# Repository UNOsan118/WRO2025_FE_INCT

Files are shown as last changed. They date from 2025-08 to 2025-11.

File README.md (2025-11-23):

# WRO 2025 Future Engineers: Team Ishikawa KOSEN Flag of Japan

<p align="center">
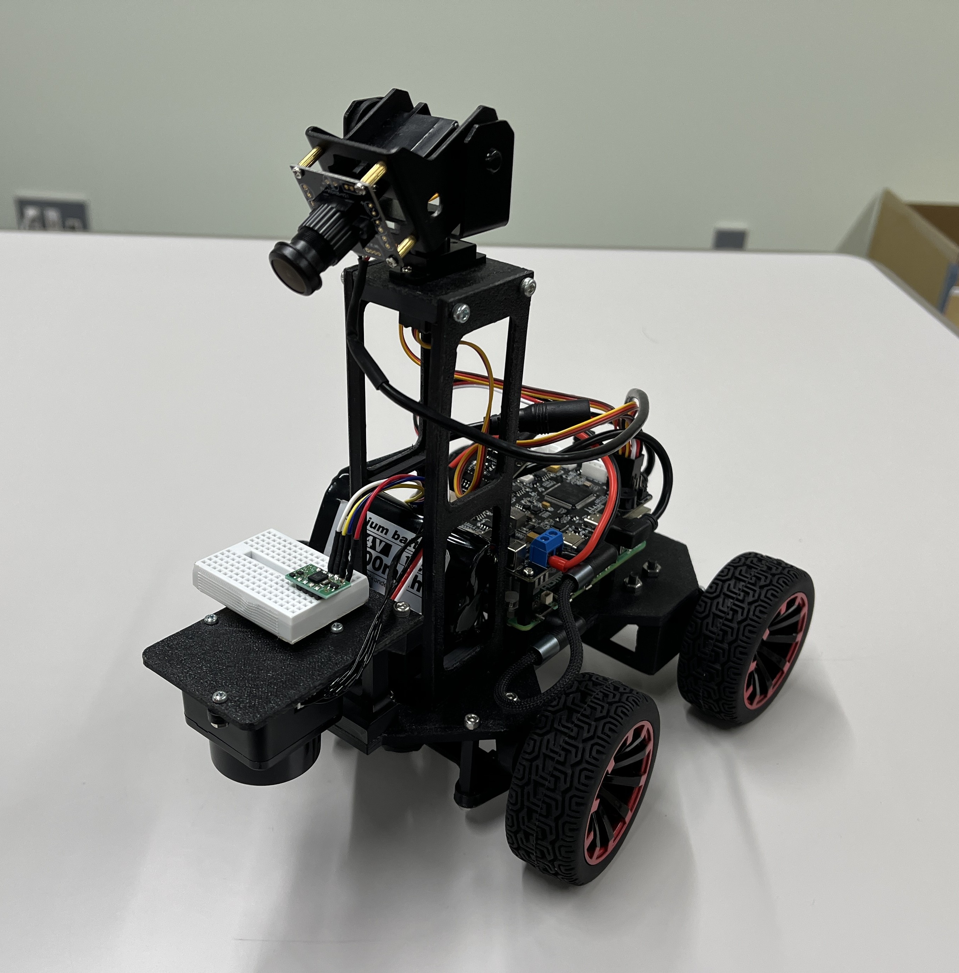
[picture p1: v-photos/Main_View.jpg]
Main_View
  
  <br>
</p>

<!-- Social media badges (optional but nice) -->



This is the official repository for **Team Ishikawa KOSEN**, representing Japan in the World Robot Olympiad (WRO) 2025 Future Engineers category. This document provides a comprehensive overview of our robot's design, strategy, and implementation, developed by Shinichi Uno and Kosei Takano.

---

## 1. Team Members & Roles

## 1.1 Team Introduction

We are Team Ishikawa KOSEN, the representatives of Japan for the WRO 2025 Future Engineers category. After winning a highly competitive national competition, we are deeply honored to compete on the world's highest stage. Our team consists of two students and one coach from the National Institute of Technology (KOSEN), Ishikawa College, an institution renowned for its rigorous, project-based engineering curriculum. It is through this hands-on approach—where theoretical knowledge is immediately applied to solve complex, real-world challenges—that we have honed the skills necessary to excel. We are fully prepared and determined to claim first place in this international competition!

<p align="center">
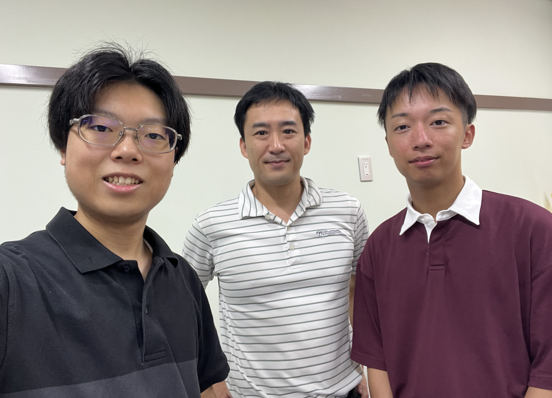
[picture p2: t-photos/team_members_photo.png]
Team members photo
  
  <br>
</p>

*   **Shinichi Uno:** Lead Programmer, Strategist & Co-Mechanical Designer
    *   *Major: Advanced Electronic and Mechanical Engineering, 2nd Year*
    *   *Born: January 18, 2004*

<p align="center">
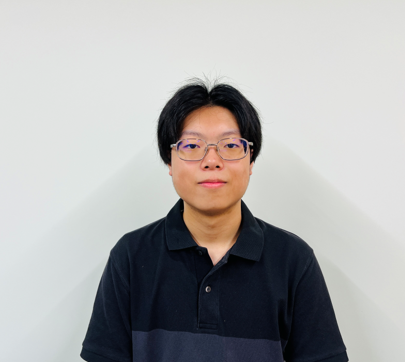
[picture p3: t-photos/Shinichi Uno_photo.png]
Team members photo
  
  <br>
</p>

*   **Kosei Takano:** Lead Mechanical Designer & Systems Integrator
    *   *Major: Advanced Electronic and Mechanical Engineering, 2nd Year*
    *   *Born: May 29, 2003*

<p align="center">
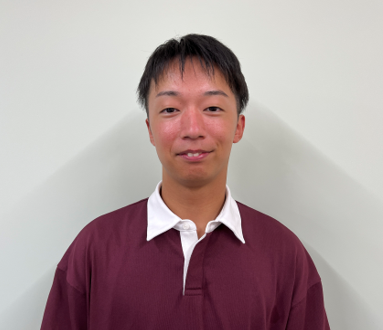
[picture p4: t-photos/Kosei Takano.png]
Team members photo
  
  <br>
</p>

*   **Makoto Koshino:** Team Coach
    *   *Professor, Department of Electronics and Information Engineering*

<p align="center">
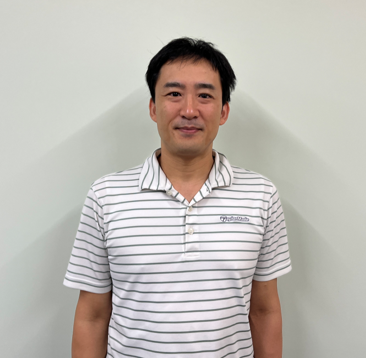
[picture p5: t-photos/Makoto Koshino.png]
Team members photo
  
  <br>
</p>

---

## 2. Repository Structure

A brief guide to navigating our project repository.

*   `src/`: Contains the core ROS 2 source code, including our main `obstacle_navigator_node`.
*   `models/`: 3D CAD files for all custom-designed and 3D-printed parts.
*   `schemes/`: Circuit diagrams, system architecture diagrams, and state-machine flowcharts.
*   `v-photos/`: A gallery of our robot from all angles.
*   `t-photos/`: Photos of our team.
*   `video/`: Performance videos demonstrating the robot's capabilities.
*   `README.md`: This file, detailing our entire engineering process.

---

## 3. Bill of Materials (BOM)

The table below lists all the major electrical and mechanical components used to build our robot. Each component was carefully selected to meet our performance and reliability requirements. Direct links to product pages or datasheets are provided to ensure the reproducibility of our design.

| Component | Image | Quantity | Link / Datasheet |
| :--- | :---: | :---: | :--- |
| **Controller & Interface** | | | |
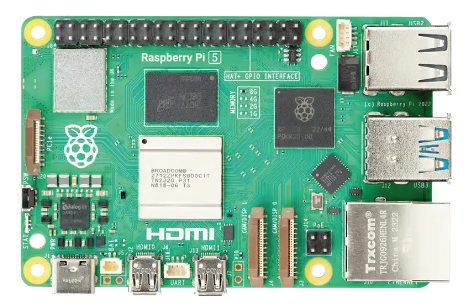
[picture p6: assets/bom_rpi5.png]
| Raspberry Pi 5 |  | 1 | [Official Page](https://www.raspberrypi.com/products/raspberry-pi-5/) |
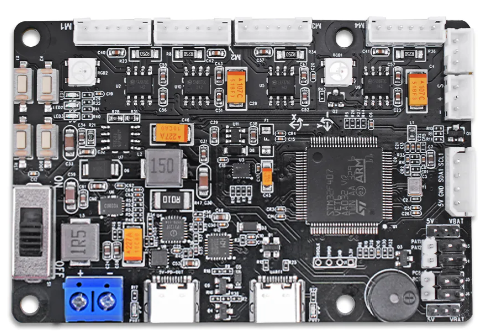
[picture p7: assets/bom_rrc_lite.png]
| RRC Lite Controller |  | 1 | [Official Page](https://www.hiwonder.com/products/rrc-lite) <br> *(Part of [MentorPi A1 kit](https://www.hiwonder.com/products/mentorpi-a1-monocular-camera-version?variant=41370001244247))*|
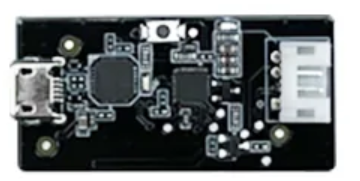
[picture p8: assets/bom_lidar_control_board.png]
| Control Board for LiDAR |  | 1 | *(Part of [MentorPi A1 kit](https://www.hiwonder.com/products/mentorpi-a1-monocular-camera-version?variant=41370001244247) and [LiDAR kit](https://www.hiwonder.com/products/ld19-d300-lidar?_pos=1&_sid=6968f314c&_ss=r) )*|
| **Sensors** | | | |
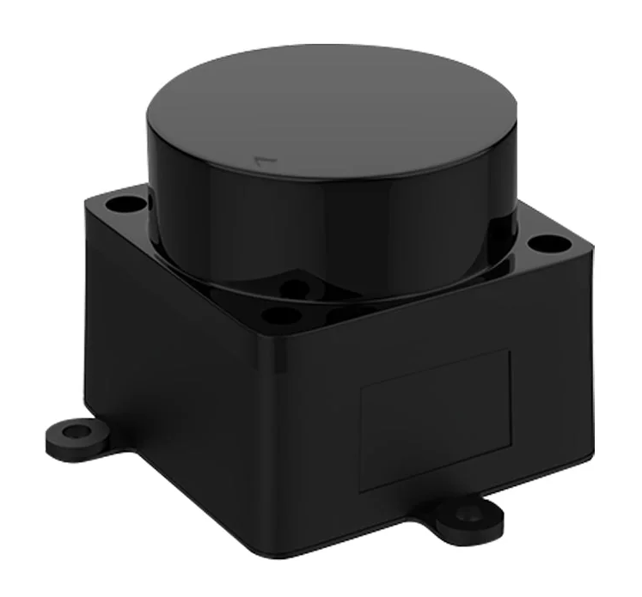
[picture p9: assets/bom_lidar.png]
| STL-19P D500 LiDAR |  | 1 | [Product Page](https://www.hiwonder.com/products/ld19-d300-lidar?_pos=1&_sid=6968f314c&_ss=r) <br> *(Part of [MentorPi A1 kit](https://www.hiwonder.com/products/mentorpi-a1-monocular-camera-version?variant=41370001244247))*|
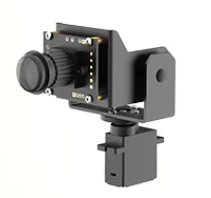
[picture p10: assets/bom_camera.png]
| 2DOF Monocular Camera |  | 1 | [Product Page](https://www.hiwonder.com/products/mentorpi-a1-monocular-camera-version?variant=41370001244247) <br> *(Part of [MentorPi A1 kit](https://www.hiwonder.com/products/mentorpi-a1-monocular-camera-version?variant=41370001244247))*|
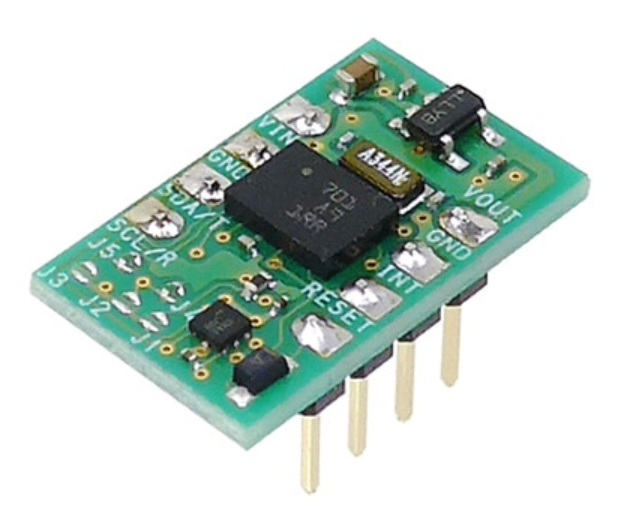
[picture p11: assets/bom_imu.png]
| BNO055 IMU |  | 1 | [Product Page](https://akizukidenshi.com/catalog/g/g116996/) |
| **Propulsion & Steering System** | | | |
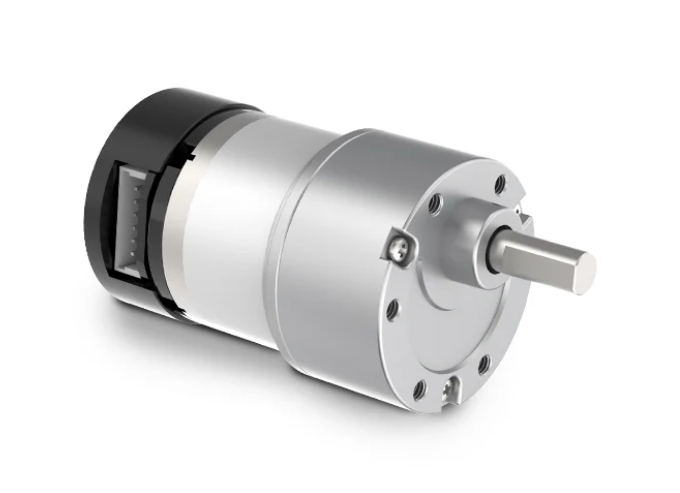
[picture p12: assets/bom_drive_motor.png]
| DC Geared Motor w/ Encoder| | 1 | [Product Page](https://www.hiwonder.com/products/hall-encoder-dc-geared-motor?variant=40451123675223) <br> *(Part of [MentorPi A1 kit](https://www.hiwonder.com/products/mentorpi-a1-monocular-camera-version?variant=41370001244247))*|
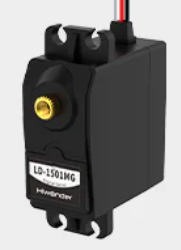
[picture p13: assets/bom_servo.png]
| Hiwonder LFD-01 Servo|  | 1 | [Product Page](https://www.aliexpress.com/i/3256805777087496.html?gatewayAdapt=jpn2glo4itemAdapt) <br> *(Part of [MentorPi A1 kit](https://www.hiwonder.com/products/mentorpi-a1-monocular-camera-version?variant=41370001244247))*|
| **Power System** | | | |
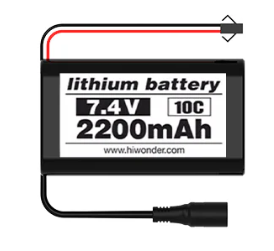
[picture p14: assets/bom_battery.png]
| 7.4V 2200mAh LiPo Battery|  | 1 | *(Part of [MentorPi A1 kit](https://www.hiwonder.com/products/mentorpi-a1-monocular-camera-version?variant=41370001244247))* |
| **Mechanical Components** | | | |
| Differential Gears |  | 1 | [Product Page](https://www.aliexpress.com/i/3256803487389220.html?gatewayAdapt=4itemAdapt) |
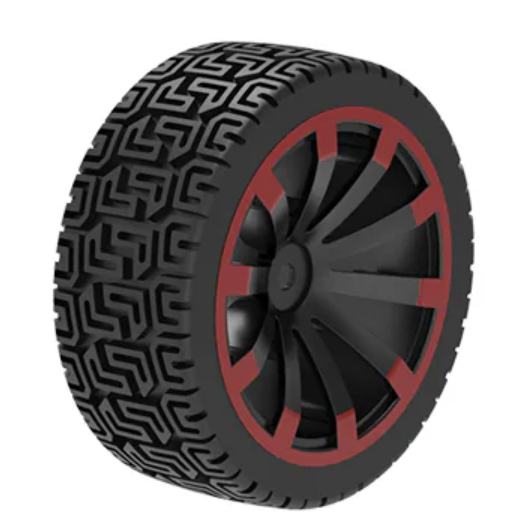
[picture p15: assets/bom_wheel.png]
| Wheels & Tires |  | 4 | *[Product Page](https://www.hiwonder.com/products/mecanum-omnidirectional-wheel-metal-coupling-motor-ros-robot-universal-wheel-smart-car-tire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) <br> (Part of [MentorPi A1 kit](https://www.hiwonder.com/products/mentorpi-a1-monocular-camera-version?variant=41370001244247))* |
| **Custom 3D-Printed Parts** | | | |
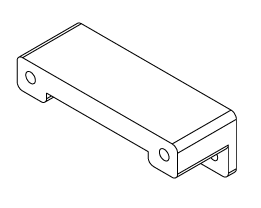
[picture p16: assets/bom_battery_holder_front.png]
| Battery Holder (Front) |  | 1 | [3D Model](models/custom_parts/cad_files/battery_holder_front.SLDPRT) / [Blueprint](models/custom_parts/blueprints/battery_holder_front.PDF) |
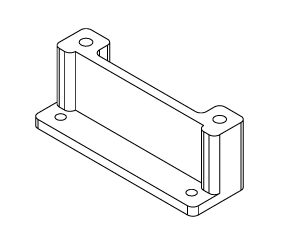
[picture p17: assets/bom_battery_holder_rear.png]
| Battery Holder (Rear) |  | 1 | [3D Model](models/custom_parts/cad_files/battery_holder_rear.SLDPRT) / [Blueprint](models/custom_parts/blueprints/battery_holder_rear.PDF) |
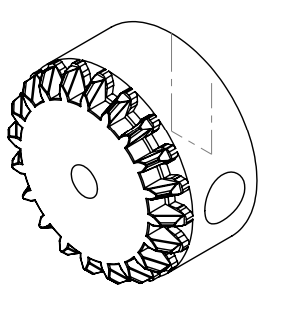
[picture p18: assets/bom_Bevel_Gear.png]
| Bevel Gear |  | 1 | [3D Model](models/custom_parts/cad_files/Bevel_Gear.SLDPRT) / [Blueprint](models/custom_parts/blueprints/Bevel_Gear.pdf) |
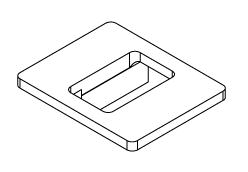
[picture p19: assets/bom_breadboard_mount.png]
| Breadboard Mount |  | 1 | [3D Model](models/custom_parts/cad_files/breadboard_mount.SLDPRT) / [Blueprint](models/custom_parts/blueprints/breadboard_mount.PDF) |
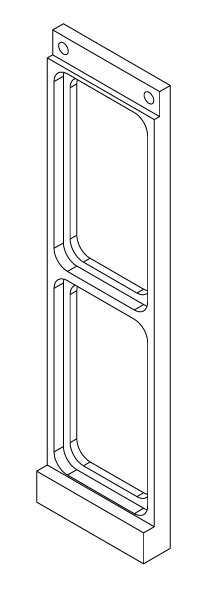
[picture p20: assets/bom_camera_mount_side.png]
| Camera Mount (Side) |  | 2 | [3D Model](models/custom_parts/cad_files/camera_mount_side.SLDPRT) / [Blueprint](models/custom_parts/blueprints/camera_mount_side.PDF) |
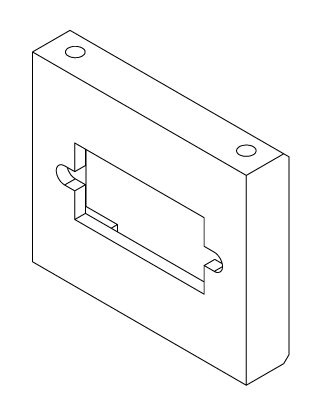
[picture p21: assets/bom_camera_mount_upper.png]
| Camera Mount (Upper) |  | 1 | [3D Model](models/custom_parts/cad_files/camera_mount_upper.SLDPRT) / [Blueprint](models/custom_parts/blueprints/camera_mount_upper.PDF) |
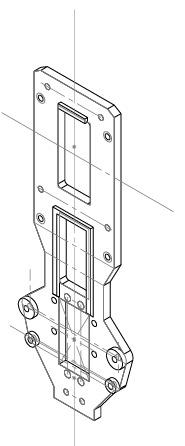
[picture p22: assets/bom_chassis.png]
| Chassis |  | 1 | [3D Model](models/custom_parts/cad_files/chassis.SLDPRT) / [Blueprint](models/custom_parts/blueprints/chassis.PDF) |
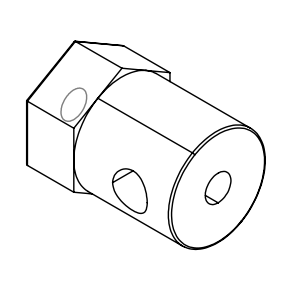
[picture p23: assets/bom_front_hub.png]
| Front Hub |  | 2 | [3D Model](models/custom_parts/cad_files/front_hub.SLDPRT) / [Blueprint](models/custom_parts/cad_files/front_hub.SLDPRT) |
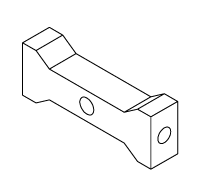
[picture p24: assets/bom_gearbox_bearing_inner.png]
| Gearbox Bearing (Inner) |  | 1 | [3D Model](models/custom_parts/cad_files/gearbox_bearing_inner.SLDPRT) / [Blueprint](models/custom_parts/blueprints/gearbox_bearing_inner.pdf) |
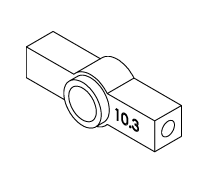
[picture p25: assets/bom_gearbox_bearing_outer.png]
| Gearbox Bearing (Outer) |  | 1 | [3D Model](models/custom_parts/cad_files/gearbox_bearing_outer.SLDPRT) / [Blueprint](models/custom_parts/blueprints/gearbox_bearing_outer.pdf) |
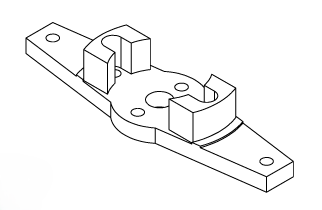
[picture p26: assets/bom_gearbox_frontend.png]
| Gearbox (Front End) |  | 1 | [3D Model](models/custom_parts/cad_files/gearbox_frontend.SLDPRT) / [Blueprint](models/custom_parts/blueprints/gearbox_frontend.PDF) |
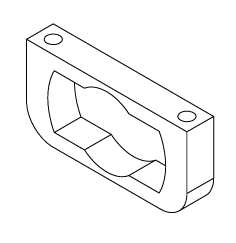
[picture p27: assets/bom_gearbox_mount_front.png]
| Gearbox Mount (Front) |  | 1 | [3D Model](models/custom_parts/cad_files/gearbox_mount_front.SLDPRT) / [Blueprint](models/custom_parts/blueprints/gearbox_mount_front.PDF) |
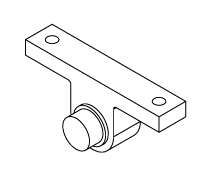
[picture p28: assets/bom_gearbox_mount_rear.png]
| Gearbox Mount (Rear) |  | 1 | [3D Model](models/custom_parts/cad_files/gearbox_mount_rear.SLDPRT) / [Blueprint](models/custom_parts/blueprints/gearbox_mount_rear.PDF) |
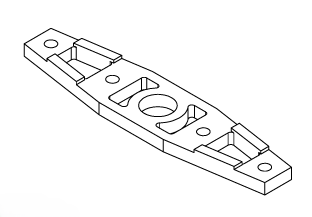
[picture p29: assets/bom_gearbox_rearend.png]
| Gearbox (Rear End) |  | 1 | [3D Model](models/custom_parts/cad_files/gearbox_rearend.SLDPRT) / [Blueprint](models/custom_parts/blueprints/gearbox_rearend.PDF) |
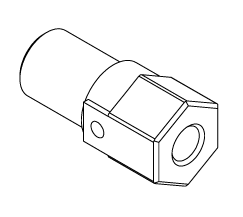
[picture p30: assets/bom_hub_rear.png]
| Hub (Rear) |  | 2 | [3D Model](models/custom_parts/cad_files/hub_rear.SLDPRT) / [Blueprint](models/custom_parts/blueprints/hub_rear.pdf) |
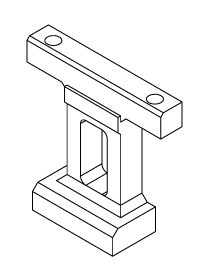
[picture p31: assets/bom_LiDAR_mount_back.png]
| LiDAR Mount (Back) |  | 1 | [3D Model](models/custom_parts/cad_files/LiDAR_mount_back.SLDPRT) / [Blueprint](models/custom_parts/blueprints/LiDAR_mount_back.PDF) |
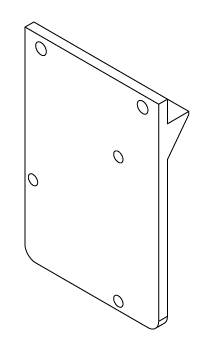
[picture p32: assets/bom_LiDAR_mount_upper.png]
| LiDAR Mount (Upper) |  | 1 | [3D Model](models/custom_parts/cad_files/LiDAR_mount_upper.SLDPRT) / [Blueprint](models/custom_parts/blueprints/LiDAR_mount_upper.PDF) |
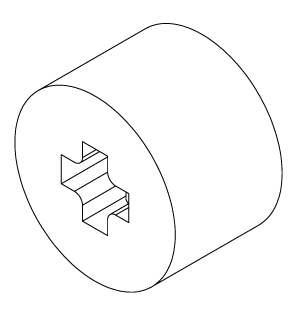
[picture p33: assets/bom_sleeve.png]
| Sleeve |  | 2 | [3D Model](models/custom_parts/cad_files/sleeve.SLDPRT) / [Blueprint](models/custom_parts/blueprints/sleeve.pdf) |
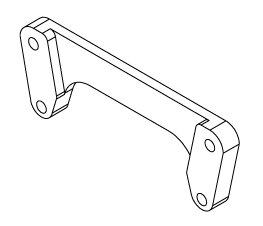
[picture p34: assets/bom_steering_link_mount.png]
| Steering Link Mount |  | 1 | [3D Model](models/custom_parts/cad_files/steering_link_mount.SLDPRT) / [Blueprint](models/custom_parts/blueprints/steering_link_mount.pdf) |

---

## 4. Vehicle Overview & Photos

A high-level introduction to our robot's design philosophy and key features.

| Front_View | Right_View | Rear_View |
| :--: | :--: | :--: |
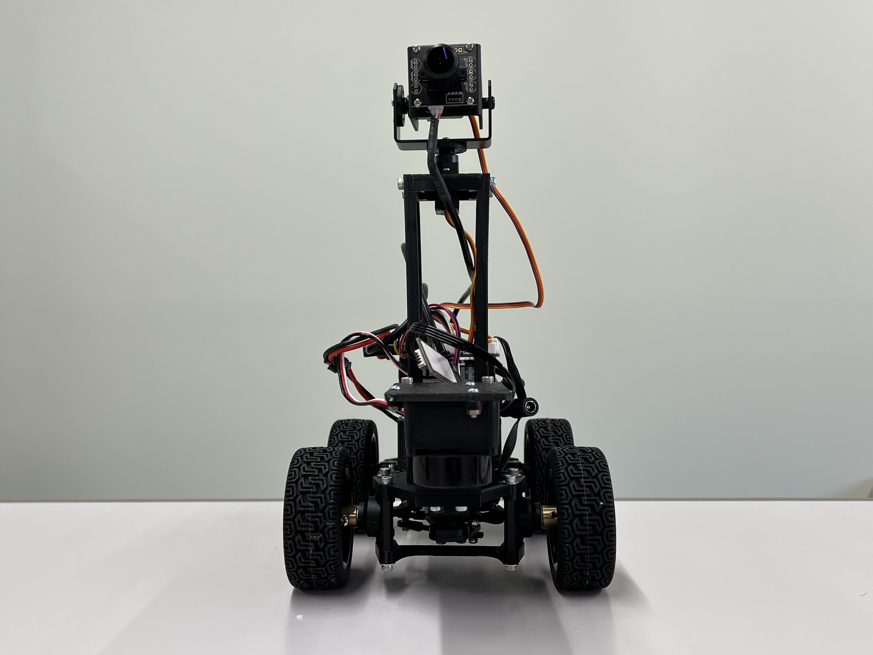
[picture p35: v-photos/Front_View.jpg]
Front_View
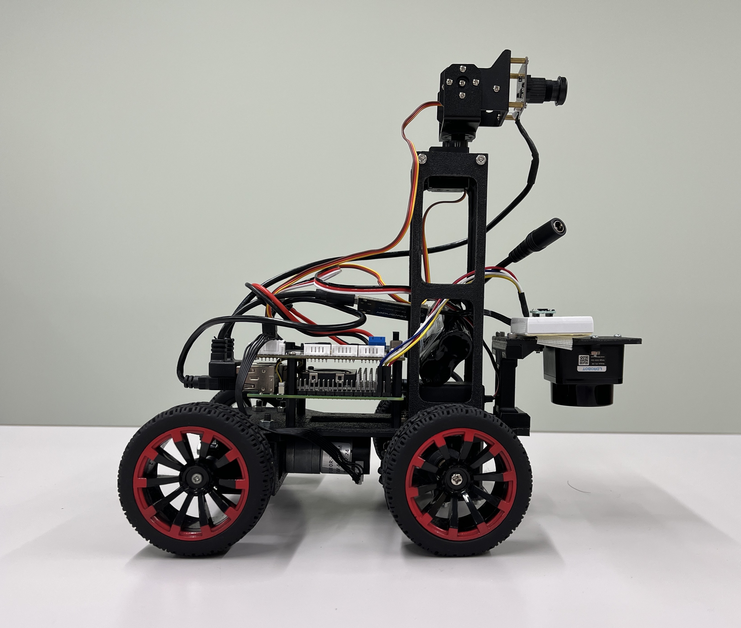
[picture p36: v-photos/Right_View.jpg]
Right_View
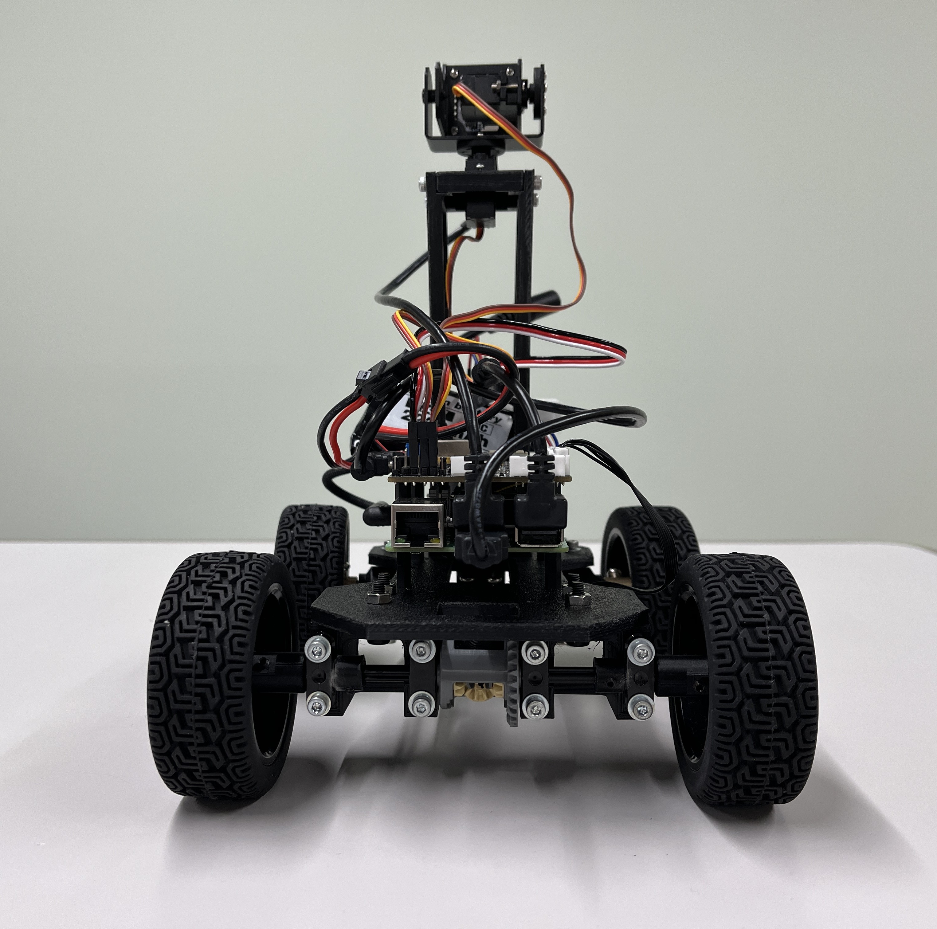
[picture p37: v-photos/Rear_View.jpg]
Rear_View
|  |  |  |
| Left_View | Top_View | Bottom_View |
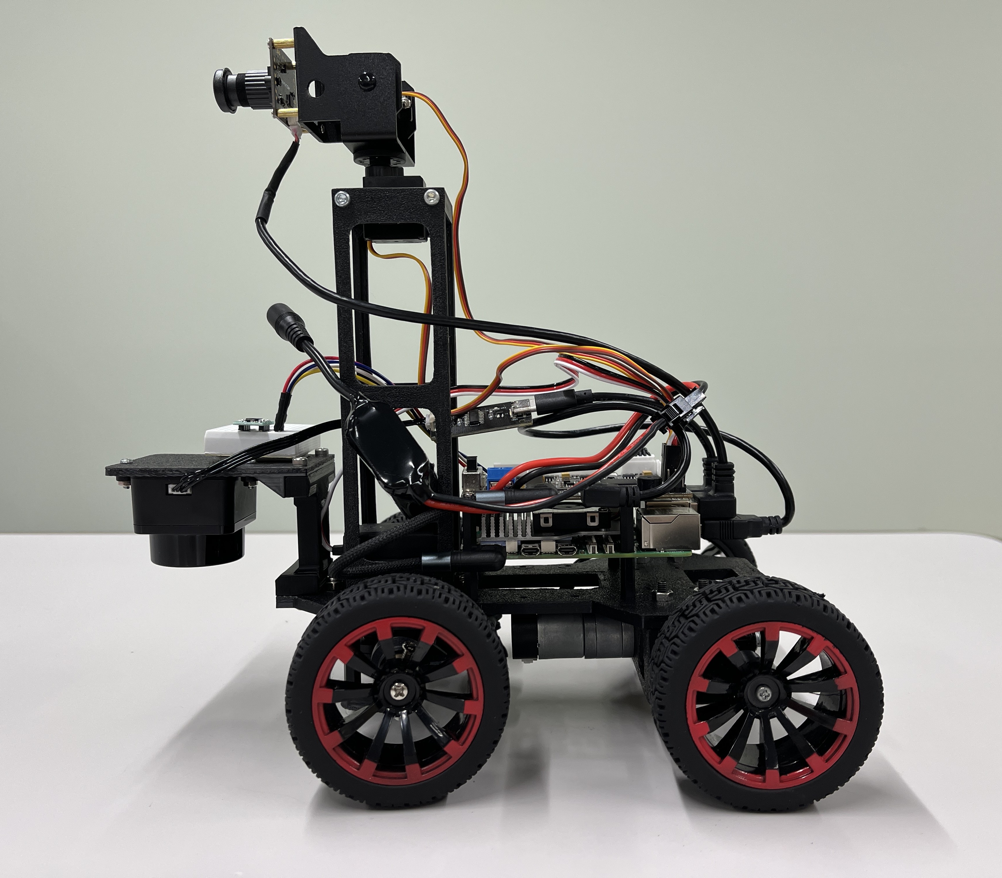
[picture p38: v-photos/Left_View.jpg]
Left_View
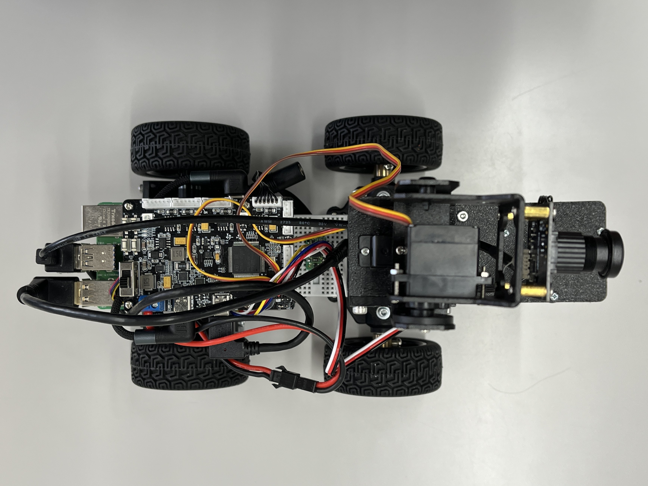
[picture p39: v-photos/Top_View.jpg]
Top_View
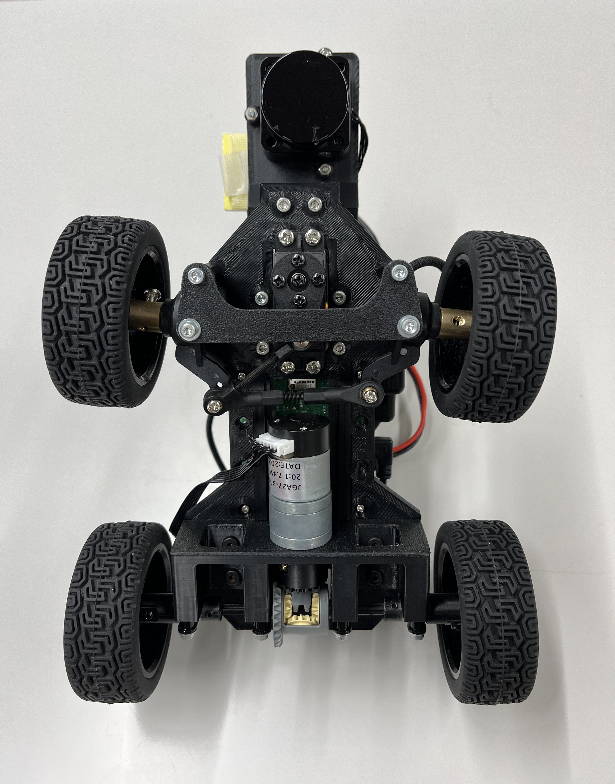
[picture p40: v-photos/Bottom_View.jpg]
Bottom_View
|  |  |  |

<p align="center">
  Power Switch and Start Button
  <br>
  <em>Power Switch and Start Button</em>
</p>

---             

## 5. Mobility Management

This section details our robot's mechanical framework, its propulsion system, and the mechanisms for directional control. Our design philosophy emphasizes precision, stability, and agile control on the competition field.

### 5.1. Chassis Design

Our robot's development began with the **Hiwonder MentorPi A1** as a base platform, which we selected for its robust initial structure. However, through extensive testing and iteration, our design has evolved into a **unique, custom chassis** that, while inspired by the original, is now tailored specifically to our strategic needs.

### 5.2. Drive Mechanism: A Custom Monoshock Differential System

#### 5.2.1. Development Story: Integrating Propulsion, Suspension, and Rule Compliance

The stock MentorPi A1 chassis featured a dual-motor drive system, which is not permitted under WRO rules as it constitutes an "electronic differential." Our primary engineering goal was to not only achieve rule compliance with a mechanical solution but to **seize this opportunity to innovate**. We decided to design a completely new rear assembly that would integrate three critical functions into one compact unit: **propulsion, differential action, and suspension**.

Our solution is a custom-designed and 3D-printed gearbox that houses a **single DC motor** and a reliable **LEGO Technic differential gear set**. Most importantly, the entire gearbox assembly is mounted to the chassis via a pivot and acts as a swingarm, effectively creating a **monoshock suspension system** for the rear axle.

#### 5.2.2. Functional Deep Dive: The Integrated Gearbox and Suspension

This integrated design offers significant performance advantages:

*   **Mechanical Differential:** The combination of our custom bevel gear and the LEGO differential ensures rule compliance while providing smooth power distribution for stable cornering. The 3D-printed housing was meticulously designed in SOLIDWORKS to guarantee a perfect and reliable gear mesh.
*   **Monoshock Suspension:** As shown in the images below, the gearbox pivots vertically, allowing the rear wheels to absorb imperfections on the track surface. This ensures that the robot can continue its run reliably even if there are unexpected bumps or irregularities on the course.

<p align="center">
  Top-down view of the custom differential gearbox
  <br>
  <em>Top-down view showcasing the custom bevel gear (top, black) meshing with the LEGO differential gear set (center, gold/grey).</em>
</p>

<p align="center">
  Rear suspension in neutral position
  Rear suspension in compressed position
  <br>
  <em>The integrated monoshock suspension system in action. The entire gearbox assembly pivots to absorb surface irregularities, maximizing traction.</em>
</p>

**Motor Selection Rationale:**
We selected this specific motor for three key reasons:
1.  **Integrated Encoder:** The built-in high-resolution encoder provides the precise feedback necessary for advanced PID speed control, eliminating the need for external sensors.
2.  **High Torque:** The 1:20 gear ratio provides sufficient torque to ensure powerful acceleration and stable performance, even on slight inclines.
3.  **Compact Form Factor:** Its compact size was ideal for our custom-designed, single-motor chassis, allowing for a clean and efficient mechanical layout.

**Motor Specifications:**
<p align="center">
  drive_motor
  Drive Motor Specifications<br>
  <em>Image and specifications sourced from <a href="https://www.hiwonder.com/products/hall-encoder-dc-geared-motor?variant=40451123675223">Hiwonder's official product page</a>.</em>
</p>

### 5.3. Steering Mechanism: Modified Ackermann Geometry

#### 5.3.1. The Challenge: A Turning Radius Unsuitable for Parking

While the stock Ackermann steering was functional for basic navigation, its limited steering angle resulted in a minimum turning radius of approximately **65 cm**. This was a critical flaw, making it physically impossible to perform the precise maneuvers required for parallel parking within a 45 cm wide space. To overcome this, a radical redesign of the entire front steering assembly was not just an optimization—it was a necessity.

#### 5.3.2. Our Solution: Vertical Motor Mount and Angled Linkage

Our solution involved redesigning the custom chassis to accommodate an innovative steering layout. By reorienting the steering servo to a **vertical position** and using an **angled transmission axis** when the wheels are straight, we achieved two critical goals simultaneously:

1.  **Space Optimization:** This compact vertical layout freed up significant space, allowing for a much greater range of motion for the steering linkage without mechanical interference.
2.  **Maximized Steering Angle:** The new geometry dramatically increased the maximum steering angle.

This redesign, while reusing most of the original mechanical linkage components, was only made possible by our custom 3D-printed chassis and mounts. The result is a steering system that achieves an incredible **minimum turning radius of just 15 cm**—a reduction of over 75%. This exceptional agility is the key enabler for our successful unparking and parking strategies.

*(Note: The evolution of our custom chassis to support this mechanism is detailed in **Section 8: Engineering Design & Manufacturing**.)*

<p align="center">
  Steering mechanism in neutral position
  Steering mechanism at full left lock
  Steering mechanism at full right lock
  <br>
  <em>Our custom steering assembly. From left to right: Neutral position showing the angled linkage, and the significantly increased maximum steering angles at full left and right lock.</em>
</p>

#### 5.3.3. Actuator and Kinematic Model

To maximize our robot's agility, we modified the stock **Ackermann steering mechanism** provided by the base vehicle. Our primary goals were to **increase the maximum steering angle** and improve overall turning precision.

*   **Principle:** The Ackermann geometry is designed so that during a turn, the inner front wheel pivots at a sharper angle than the outer wheel. This ensures that the normal lines of all four wheels intersect at a single Instantaneous Center of Rotation (ICR), minimizing tire slippage.
*   **Effect:** By adhering to this principle while modifying the linkage for a greater steering range, we have achieved exceptionally smooth and predictable cornering, especially in tight turns. This allows for more energy-efficient and faster navigation through the course.

The steering is actuated by a **Hiwonder LFD-01 Anti-blocking Servo**.

**Servo Selection Rationale:**
Our choice of this servo was deliberate, focusing on reliability and power.
1.  **High Torque & Metal Gears:** To handle the stresses of rapid, precise steering adjustments at speed, we needed a servo with high torque and durable metal gears. This prevents gear stripping, a common failure point with standard servos.
2.  **Anti-Blocking Feature:** This servo includes a built-in protection circuit that prevents damage if the steering mechanism becomes stalled or blocked, significantly increasing the robot's overall robustness during long runs.

**Motor Specifications:**
<p align="center">
  Steering Motor Specifications<br>
<em>Image and specifications sourced from <a href="https://www.hiwonder.com/products/ackermann-steering-chassis?variant=40382428348503">Hiwonder's official product page</a>.</em>
</p>

#### Kinematic Model

To mathematically model our robot's motion and ensure pure rolling without lateral slip, we applied the following kinematic principles based on the Ackermann model.

<p align="center">
  Ackermann Kinematic Model
</p>

**Key Parameters:**
*   **θ:** Front wheel steering angle (rad).
*   **V:** Linear velocity of the vehicle (m/s), with V<sub>L</sub> and V<sub>R</sub> being the left and right rear wheel velocities.
*   **D:** Track width of the vehicle (m).
*   **H:** Wheelbase of the vehicle (m).
*   **R:** Turning radius of the vehicle (m), with R<sub>L</sub> and R<sub>R</sub> being the radii for the left and right wheels.
*   **ω:** Angular velocity of the vehicle (rad/s).

**Core Formulas:**

1.  **Angular Velocity Consistency:** The angular velocity is consistent across the vehicle.
    <p align="center">
      Formula for Angular Velocity
    </p>

2.  **Relationship between Steering Angle and Turning Radius:** The turning radius is geometrically related to the steering angle and wheelbase.
    <p align="center">
      Formula for Turning Radius
    </p>
    
3.  **Individual Wheel Velocities:** By knowing the wheelbase, track width, vehicle speed, and servo steering angle, we can calculate the required velocity for each rear wheel. This difference in speed is physically realized by our differential gearbox.
    *   **Left Wheel Velocity (V<sub>L</sub>):**
        <p align="center">
          Formula for Left Wheel Velocity
        </p>

    *   **Right Wheel Velocity (V<sub>R</sub>):**
        <p align="center">
          Formula for Right Wheel Velocity
        </p>

This mathematical model is fundamental to how our `ros_robot_controller` translates high-level velocity commands into precise, differential wheel speeds, enabling accurate path following.

---

## 6. Power and Sense Management

This section details the robot's "lifeline," its power system, and its "senses," the suite of sensors that enables it to perceive the environment. A stable power supply and accurate environmental awareness are the most critical physical foundations for our autonomous navigation strategy.

### 6.1. Power System

**The Challenge:**
An autonomous robot must reliably power a powerful computational core (SBC), multiple sensors, and high-torque motors simultaneously. A significant challenge is the voltage drop that occurs during motor acceleration, which can lead to critical failures like SBC reboots or sensor errors.

**Our Solution:**
To overcome this, we have built a robust power system by combining reliable, high-performance components.

**1. Battery Selection:**
Our primary power source is a **7.4V 2200mAh 10C LiPo Battery**.

*   **Selection Rationale:**
    *   **Sufficient Capacity:** The 2200mAh capacity ensures stable performance throughout the entire duration of a competition run.
    *   **High Discharge Rate:** A high C-rate of `10C` allows the battery to comfortably handle the large peak currents demanded by the motors during acceleration, minimizing voltage drops.
    *   **Integrated BMS:** The battery includes a built-in Battery Management System (BMS) that protects against over-charge, over-discharge, over-current, and short circuits, significantly enhancing safety during testing and competition.

<p align="center">
  7.4V 2200mAh LiPo Battery
</p>

**2. Power Distribution and Stabilization:**
Power from the battery is distributed to our main components—the **Raspberry Pi, motors, and LiDAR**—via the **Hiwonder RRC Lite Controller**.

*   **Role:** This controller acts as an intelligent hub, providing stable, regulated power to these power-hungry components.
*   **Key Advantage:** A critical feature of this controller is its support for the **Power Delivery (PD) protocol**, enabling it to supply a stable **5V/5A** current to the Raspberry Pi 5. This powerful supply capability isolates the Raspberry Pi from voltage sags caused by motor operation, eliminating the risk of unexpected shutdowns or system instability. This forms the bedrock of our robot's high reliability.

<p align="center">
  RRC Lite Controller
</p>

### 6.2. Sensor Suite

Our robot fuses data from multiple sensors, each with a distinct role, to build a comprehensive and accurate understanding of its environment. All sensor data is aggregated in real-time by our main `ObstacleNavigatorNode` via ROS 2 topics to inform its navigation decisions.

#### STL-19P D500 LiDAR

<p align="center">
    STL-19P D500 LiDAR
    LiDAR Specifications
    <em><br>Image and specifications sourced from the <a href="https://www.hiwonder.com/products/ld19-d300-lidar?_pos=1&_sid=6968f314c&_ss=r">official product page</a>.</em>
</p>

**Role:** This is our primary sensor for environmental mapping. It provides 360-degree distance information, which is fundamental for wall detection, corner detection, and initial obstacle localization.

*   **Selection Rationale:** We chose this model for its high-speed, 360-degree scanning capability and its excellent ROS 2 driver support, which facilitated easy integration. Its TOF (Time of Flight) technology also ensures stable and reliable measurements.
*   **Software Integration:** Data from the `/scan` topic is fused with IMU data in our `get_distance_at_world_angle()` function. This corrected data serves as the core input for our `_execute_pid_alignment()` (wall-following) and `_check_for_corner()` (corner detection) algorithms.

*Code Snippet: Subscribing to LiDAR Data*
```python
# This code in __init__ starts listening to the /scan topic.
# The scan_callback function is called every time new data arrives.
self.scan_subscriber = self.create_subscription(
    LaserScan, 
    '/scan', 
    self.scan_callback, 
    qos_profile_lidar
)
```

#### 2DOF Monocular Camera

<p align="center">
    2DOF Monocular Camera
    Camera Specifications
    <em><br>Image and specifications sourced from the <a href="https://www.hiwonder.com/products/mentorpi-a1-monocular-camera-version?variant=41370001244247">official product page</a>.</em>
</p>

**Role:** Our vision sensor, used exclusively for identifying the **color** of obstacles.

*   **Selection Rationale:** The 170° wide-angle lens is a key feature, allowing the robot to capture a broad view of the upcoming segment during its corner scans. Its USB interface and ROS 2 compatible driver ensure seamless integration with the Raspberry Pi.
*   **Software Integration:** Image frames from the `/ascamera/...` topic are processed during the `PLAN_NEXT_AVOIDANCE` phase. Using OpenCV, we detect red and green blobs and compare their areas to determine the `avoidance_path_plan` for the next segment.

*Code Snippet: Subscribing to Camera Data*
```python
# This code in __init__ subscribes to the camera's image topic.
# The image_callback function processes the incoming video frames.
self.image_sub = self.create_subscription(
    Image, 
    '/ascamera/camera_publisher/rgb0/image', 
    self.image_callback, 
    qos_profile_img
)
```

#### IMU (BNO055)

<p align="center">
    BNO055 IMU
    Camera Specifications
    <em><br>Image and specifications sourced from the <a href="https://akizukidenshi.com/catalog/g/g116996/">official product page</a>.</em>
</p>

**Role:** This Inertial Measurement Unit measures the robot's orientation (yaw angle), acting as a crucial component that dramatically enhances navigation precision.

*   **Selection Rationale:** Although the RRC Lite Controller has an onboard IMU, we opted for the external BNO055 for its superior accuracy and stability. Its internal 9-axis sensor fusion algorithms provide a reliable, low-drift heading estimate.
*   **Software Integration:** The yaw data from the `/imu/yaw` topic is **essential for correcting the LiDAR data** in our `get_distance_at_world_angle()` function. This is how we overcome the "Black Wall Problem," ensuring accurate wall distance measurements regardless of the robot's orientation.

*Code Snippet: Subscribing to IMU Data*
```python
# This code in __init__ subscribes to the IMU's yaw topic.
# The yaw_callback function updates the robot's current heading.
self.yaw_subscriber = self.create_subscription(
    Float64, 
    '/imu/yaw', 
    self.yaw_callback, 
    10
)
```

### 6.3. Wiring Diagram

The following diagram illustrates the complete electrical connections between our core components, including the Raspberry Pi, RRC Lite Controller, battery, and all sensors. This centralized wiring, managed by the RRC Lite Controller, simplifies the overall structure and enhances reliability by minimizing potential points of failure.

<p align="center">
  Robot Wiring Diagram
</p>

A detailed list of all the components shown in this diagram is available in [**Section 3: Bill of Materials (BOM)**](#3-bill-of-materials-bom).

---

## 7. Obstacle Management Strategy

This is the core of our autonomous navigation logic, implemented in the `obstacle_navigator_node.py`.

### 7.1. Overall Strategy: A Hierarchical State Machine

To navigate the complex and dynamic environment of the WRO course, our robot employs a **Hierarchical State Machine (HSM)**. This software architecture allows us to systematically manage the robot's behavior by breaking down the overall task into a series of distinct, manageable states. The robot always knows its current state and transitions to the next state based on clear, predefined conditions derived from sensor data.

This approach ensures robust, predictable, and debuggable behavior. The system is built around six main states, each responsible for a specific phase of the mission.

**Main States Overview:**

*   **`PREPARATION`**: Initializes all systems, including the camera and sensors, and determines the overall course direction (CW/CCW) at the start. (Parking Start Only)
*   **`UNPARKING`**: Executes a dynamic, pre-planned strategy to safely exit the parking area and enter the main course. (Parking Start Only)
*   **`STRAIGHT`**: The primary driving state. The robot follows the wall using PID control, detects upcoming corners, and plans its avoidance strategy for the next segment.
*   **`TURNING`**: Executes a precise, multi-step pivot turn to navigate the 90-degree corners of the course.
*   **`PARKING`**: Upon completing the required number of laps, this state manages the final maneuver to park the robot safely in the designated area.
*   **`FINISHED`**: The final state where all motors are stopped, concluding the run.

The core of our robot's operation is the cyclical transition between the `STRAIGHT` and `TURNING` states, which allows it to repeatedly navigate the course segments and corners.

**High-Level State Transition Flowchart:**

<p align="center">
    State Flowchart
</p>

### 7.2. The ROS 2 Ecosystem: How Our Nodes Collaborate

Our autonomous navigation system is built entirely on the **Robot Operating System 2 (ROS 2)**, an advanced, open-source framework for robotics. ROS 2 allows us to structure our software in a modular and robust way, where independent programs called **Nodes** communicate with each other in real-time.

The core of this communication is the **Publish/Subscribe (Pub/Sub)** model. Sensor nodes "publish" data onto named channels called **Topics**, and our main logic node "subscribes" to these topics to receive the data. Similarly, our logic node publishes control commands, which the motor controller node subscribes to. This decoupled architecture makes the system highly flexible, scalable, and easy to debug.

Our system consists of three primary nodes that work in concert:

1.  **Sensor Drivers Node(s):** Responsible for interfacing with the hardware (LiDAR, IMU, Camera) and publishing their raw data to ROS 2 topics.
2.  **`ObstacleNavigatorNode` (The Brain):** This is the central logic node that we developed. It subscribes to all sensor data, processes it through the hierarchical state machine, makes decisions, and publishes velocity and servo commands.
3.  **Motor Controller Node (`ros_robot_controller`):** This node subscribes to the commands from our "Brain" and translates them into low-level electrical signals to control the motors and servos.

The following diagram illustrates the flow of data between these nodes.

**Node and Topic Communication Diagram:**

<p align="center">
    Unparking Strategies
</p>

### 7.3. Dynamic Strategy Selection

A key feature of our robot is its ability to dynamically select the optimal strategy in real-time, rather than following a single, hard-coded path. This adaptability is crucial for handling the various challenges on the course. We have implemented two primary dynamic selection systems: one for unparking and one for cornering.

#### 7.3.1. Unparking Strategy (4 Patterns)

**The Challenge:** Our initial approach was to exit the parking area first and then identify the obstacle color, but this resulted in significant time loss and inefficient movements. We realized that since the obstacle is visible from the starting position, a pre-emptive scan could optimize the entire sequence. The problem then became how to reliably select an exit strategy before moving, using only a single, potentially noisy, initial observation.

**Our Solution:** To address this, our robot executes a pre-unparking check to gather data and select one of four specialized exit strategies.

1.  **Direction Detection:** The robot first uses its LiDAR to determine the course direction by measuring the distance to the side walls.
2.  **Obstacle Proximity Scan:** It then aims its camera towards the exit and analyzes the size of the detected obstacle blob to determine if it is "close" or "far".
3.  **Strategy Selection:** Based on these two pieces of information, the robot selects the most appropriate strategy from the following decision matrix:

| Course Direction | Obstacle Presence | Selected Strategy | Description |
| :--- | :--- | :--- | :--- |
| **Clockwise** | Far | `STANDARD_EXIT_TO_OUTER_LANE` | A standard turn onto the wider outer lane. |
| **Clockwise** | Far (Red Obstacle) | `STANDARD_EXIT_TO_INNER_LANE` | A standard turn onto the tighter inner lane. |
| **Clockwise** | Close (Red Obstacle) | `AVOID_EXIT_OBSTACLE_TO_INNER_LANE_CW` | A complex maneuver involving a forward push and turn to clear the obstacle. |
| **Counter-Clockwise**| Far | `STANDARD_EXIT_TO_OUTER_LANE` | A standard turn onto the wider outer lane. |
| **Counter-Clockwise**| Close | `AVOID_EXIT_OBSTACLE_TO_INNER_LANE_CCW`| A reverse maneuver to create space before turning onto the inner lane. |

<p align="center">
    Unparking Strategies
</p>

This intelligent selection process ensures a safe and efficient exit from the parking area, regardless of the initial conditions.

#### 7.3.2. Obstacle Planning Strategy: Proactive Corner Scanning

**The Challenge:**
Simply reacting to obstacles as they appear during high-speed driving is inefficient and risky. It takes too long to detect and process obstacles in real-time, leading to abrupt stops and suboptimal paths.

**Our Solution:**
Instead of reacting, we adopted a **proactive planning strategy**. Before entering a straight segment, the robot stops at the corner, scans the entire upcoming segment for obstacles, and decides on a complete path plan in advance. This "scan-then-drive" approach has a powerful advantage: the obstacle layout is determined only on the first lap, and this plan is reused on subsequent laps, allowing for much faster, smoother, and more confident driving.

This planning phase consists of three key steps:

1.  **Pre-Scan Positioning:**
    On the first lap, upon detecting a corner, the robot doesn't immediately turn. Instead, it precisely positions itself at a safe, optimal vantage point. Using its IMU for orientation correction, it aims its camera directly down the upcoming straight segment, ensuring a clear and stable view for the scan.

2.  **"Move-and-Scan" with Max-Blob Detection:**
    After positioning, the robot creeps forward very slowly while its camera continuously scans the segment. For each frame, it detects red and green obstacle "blobs" and calculates their area. To guard against sensor noise or fleeting changes in lighting, we don't rely on a single image. Instead, the final decision is based on the **largest blob area detected across the entire scan period**. This max-blob approach makes our detection system extremely robust. During this phase, the robot also specifically determines if an obstacle is blocking the entrance to the segment.

<p align="center">
  Camera view during planning scan
  Blob detection result
  <br>
  <em>Left: The raw camera view during a proactive scan. Right: The processed result, where only the detected red and green blobs are isolated for area calculation.</em>
</p>

The data from this scan is then analyzed to make a final decision. The image below shows the actual log output from our robot's analysis process. Over a scan of 36 frames, it found the largest green blob (area: 2122.0) to be significantly larger than the largest red blob and the detection threshold, leading to the final decision of a `'green_to_red'` obstacle pattern.

<p align="center">
  Log output of planning analysis
  <br>
  <em>The actual log output, showing the data-driven decision process.</em>
</p>

3.  **Path Plan Generation (4 Patterns):**
    The result of the scan (e.g., "red only," "green-to-red") is combined with the current driving direction (CW/CCW) to select one of four possible avoidance plans for the next segment: `outer-only`, `inner-only`, `outer-to-inner`, or `inner-to-outer`. This decision is stored in our `avoidance_path_plan` array. This array acts as a complete "blueprint" for the course, enabling the robot to navigate smoothly on the second and third laps by simply referencing the plan without needing to scan again.

#### 7.3.3. Straight Strategy: PID Control and Obstacle Avoidance

**The Challenge:** The "straight" segments of the course are the most critical sections, as this is where obstacles are physically present. The robot must perform two core tasks in tandem: maintaining a precise, stable trajectory along a wall, while simultaneously executing smooth maneuvers to bypass these obstacles.

**Our Solution:** The `STRAIGHT` state is our answer to this challenge. Its logic is composed of three primary actions that work together to achieve fast and safe navigation.

1.  **Wall Approach (The "Turn-In" Maneuver):**
    This is the first and most crucial phase of obstacle avoidance. Instead of attempting to swerve around an obstacle, the robot executes a deliberate **"Turn-In"** maneuver (`AVOID_*_TURN_IN` sub-state). It purposefully steers towards the opposite wall at a sharp, predefined angle. This action proactively creates the necessary space to bypass the upcoming obstacle safely and predictably.

2.  **PID Wall-Following (Align and Pass):**
    This is the core of our stable driving logic. Whether driving normally or passing an obstacle, the robot uses a robust **PID (Proportional-Integral-Derivative) controller**. This system continuously fuses data from the **IMU** (for heading) and **LiDAR** (for distance) to make constant, minute steering corrections. This allows the robot to maintain a precise distance from its reference wall, ensuring a perfectly straight and stable trajectory. During an avoidance maneuver, this same logic is used to align with the *opposite* wall and glide past the obstacle.

<p align="center">
  PID Wall-Following Principle
  <br>
  <em><b>For the case shown in this image,</b> the PID controller calculates two opposing commands. The <b>LiDAR</b>, detecting the robot is too far, generates a <em>Distance Error</em> commanding a <b>turn to the left</b>. Simultaneously, the <b>IMU</b>, detecting the inward angle, generates a <em>Heading Error</em> commanding a <b>turn to the right</b>. The final steering output is a weighted sum of these values, resulting in a smooth correction back to the target path.</em>
</p>

3.  **Lane Change for Complex Scenarios:**
    For the most challenging course layouts, our robot employs advanced lane change logic. **If both a red and a green obstacle exist within the same straight segment, the robot will execute a full lane change maneuver after clearing the first obstacle to position itself for the second.** This corresponds to our pre-planned strategies like `outer_to_inner` and ensures the robot can fluidly navigate even the most complex obstacle combinations without stopping.

#### 7.3.4. Turning Strategy (8 Patterns)

**The Challenge:** Simply making a 90-degree turn at every corner is inefficient. The optimal turning maneuver (e.g., approach distance, turn angle) depends on the robot's current path, its planned path for the *next* segment, and any obstacles present at the corner's entrance.

**Our Solution:** Our `_get_turn_strategy()` function acts as a dynamic decision-maker before every turn. It analyzes three key factors to select the best set of turning parameters from 8 possible combinations:

1.  **Current Lane:** Is the robot currently on the `Outer` or `Inner` path?
2.  **Next Lane Plan:** Is the plan for the next segment `Outer`, `Inner`, `Outer-to-Inner`, or `Inner-to-Outer`?
3.  **Entrance Obstacle:** Is there an obstacle detected at the entrance of the corner that requires a wider turn?

Based on these factors, the robot adjusts its behavior, allowing for tighter, faster turns when the path is clear, and safer, wider turns when navigating complex transitions or obstacles. This logic is the core of our robot's lap-time performance and reliability.

<p align="center">
    Unparking Strategies
</p>
<p align="center">
    Unparking Strategies
</p>

#### 7.3.5. Parking Preparation Strategy (3 Patterns)

**The Challenge:** The final parking maneuver requires the robot to be in a specific state: approaching the parking area from the **outer lane** in the **counter-clockwise (CCW)** direction. However, after completing its final lap, the robot could be in one of several states (e.g., traveling clockwise, or on the inner lane). A "one-size-fits-all" approach to parking would be inefficient and unreliable.

**Our Solution:** Upon completing the required number of laps, our robot enters the `PREPARE_PARKING` sub-state. Here, it analyzes its final state (direction and lane) and dynamically selects one of three distinct preparation strategies to ensure it always enters the final parking approach from the optimal starting condition.

| Final Lap State | Selected Strategy | Maneuver Description |
| :--- | :--- | :--- |
| **CW, Outer/Inner Lane** | `REORIENT_FOR_PARKING` | Executes a precise U-turn (either a 3-point or S-curve turn depending on the lane) to reverse its direction to CCW on the outer lane. |
| **CCW, Inner Lane** | `LANE_CHANGE_FOR_PARKING`| Performs a specialized S-curve reverse maneuver to safely move from the inner lane to the outer lane. |
| **CCW, Outer Lane** | **(Direct Proceed)** | This is the ideal state. No special maneuver is needed, and the robot transitions directly to the final `APPROACH_PARKING_START` phase. |

This dynamic selection ensures that, no matter how the final lap ends, the robot is perfectly positioned to execute a consistent and highly reliable final parking sequence.

<p align="center">
  Parking Preparation Strategies Diagram
  <br>
  <em>Visual diagram of the dynamic parking preparation strategies. The top row shows the U-turn maneuvers for a Clockwise finish, while the bottom row shows the maneuvers for a Counter-Clockwise finish.</em>
</p>

### 7.4. Key Algorithms & Engineering Decisions

Our robot's reliability is not the result of a single piece of code, but the evolution of several key algorithms born from trial and error. This section details the engineering decisions behind our most critical navigation functions.

#### 7.4.1. State Definitions (Enums)

The foundation of our HSM is explicitly defined in the code using Python's `Enum` class. This approach provides a highly readable and robust way to manage the robot's state, as summarized in the table below.

| Class Name | Role in the State Machine |
| :--- | :--- |
| **`State` (Main States)** | Defines the highest-level phases of the robot's mission, such as `STRAIGHT` or `TURNING`. It represents the robot's major operational mode. |
| **Sub-State Enums**<br>(e.g., `StraightSubState`) | For each complex Main State, a corresponding Sub-State Enum breaks down the task into a sequence of smaller, manageable actions like `PLAN_NEXT_AVOIDANCE`. |
| **`UnparkingStrategy`** | Distinct from a state, this Enum defines the *strategic plan* selected during `PREPARATION`. It dictates which multi-step unparking sequence the robot will execute. |

**Code Snippets:**

The following code snippets from `obstacle_navigator_node.py` show how these concepts are implemented.

*Main States:*
```python
class State(Enum):
    PREPARATION = auto()
    UNPARKING = auto()
    STRAIGHT = auto()
    TURNING = auto()
    PARKING = auto()
    FINISHED = auto()
```
Example of Sub-States (for the STRAIGHT state):
```python
class StraightSubState(Enum):
    ALIGN_WITH_OUTER_WALL = auto()
    ALIGN_WITH_INNER_WALL = auto()
    PLAN_NEXT_AVOIDANCE = auto()
    PRE_SCANNING_REVERSE = auto()
    AVOID_OUTER_TURN_IN = auto()
    AVOID_INNER_TURN_IN = auto()
```

Example of a Strategy Definition:
```python
class UnparkingStrategy(Enum):
    STANDARD_EXIT_TO_OUTER_LANE = auto()
    AVOID_EXIT_OBSTACLE_TO_INNER_LANE_CCW = auto()
    UNDEFINED = auto()
```

This clear and explicit state definition is the key to our robot's reliable and predictable behavior.

#### 7.4.2. Initialization & Parameters (`__init__`)

The constructor of our `ObstacleNavigatorNode` (`__init__` function) is called once when the node launches. It is responsible for preparing all the necessary components and settings for the robot to operate.

The primary roles of the `__init__` function are as follows:

*   **Initializing State Variables:**
    It defines the initial state of the system, such as setting the starting state of our state machine to `PREPARATION`.

    ```python
    # Set the initial state for the state machine
    self.state = State.PREPARATION
    self.preparation_sub_state = PreparationSubState.WAITING_FOR_CONTROLLER
    ```

*   **Centralizing Tuning Parameters:**
    All tunable parameters that define the robot's behavior—such as driving speed, PID gains, and turning distances—are defined here. This centralizes all tuning work in one location, making the system highly maintainable.

    ```python
    # --- Driving & Speed Control ---
    self.forward_speed = 0.2
    # --- Alignment (PID) ---
    self.align_kp_dist = 7.5
    ```

*   **Setting up ROS 2 Communications:**
    It configures all the necessary ROS 2 communication channels, including Subscribers to receive sensor data and Publishers to send commands to the motors.

    ```python
    # Subscriber for LiDAR data
    self.scan_subscriber = self.create_subscription(
        LaserScan, '/scan', self.scan_callback, qos_profile_lidar)
    ```

*   **Starting the Main Control Loop:**
    Finally, it starts a 50Hz timer that repeatedly calls our main logic function, `control_loop_callback()`, effectively kicking off the autonomous control process.

    ```python
    # Create a timer to call the main control loop at 50Hz
    self.control_loop_timer = self.create_timer(
        1.0 / 50.0, self.control_loop_callback)
    ```

#### 7.4.3. Main Control Loop & State Dispatch

The `control_loop_callback()` function, triggered at 50Hz by the timer set in `__init__`, is the "heartbeat" of our autonomous system. With every call, the robot perceives its environment and decides its next action.

##### 7.4.3.1. Role as a Central Dispatcher

The design of this function is intentionally simple. Its sole responsibility is to act as a **central dispatcher**, delegating the actual work to specialized handler functions based on the robot's current state.

The process is straightforward:
1.  **Check the current main state** stored in the `self.state` variable (e.g., `State.STRAIGHT`).
2.  **Call the corresponding handler** using an `if/elif` structure (e.g., `_handle_state_straight()`).

```python
# The core of the main loop: a simple, clean state dispatcher.
def control_loop_callback(self):
    # ...
    if self.state == State.PREPARATION: 
        self._handle_state_preparation(msg) 
    elif self.state == State.UNPARKING:
        self._handle_state_unparking(msg) 
    elif self.state == State.STRAIGHT:
        self._handle_state_straight(msg)
    # ... and so on for all other main states
```

##### 7.4.3.2. Hierarchical Delegation

This delegation process is hierarchical. Each main state handler, such as _handle_state_straight(), further dispatches the task to a sub-state handler based on the current sub-state (e.g., StraightSubState.AVOID_OUTER_TURN_IN).

```python
# Inside a main state handler, it dispatches again to a sub-state handler.
def _handle_state_straight(self, msg):
    if self.straight_sub_state == StraightSubState.ALIGN_WITH_OUTER_WALL:
        self._handle_straight_sub_align_with_outer_wall(msg)
    elif self.straight_sub_state == StraightSubState.AVOID_OUTER_TURN_IN:
        self._handle_straight_sub_avoid_outer_turn_in(msg)
    # ... and so on for all other sub-states
```

This elegant structure of hierarchical delegation is the engine that drives our state machine. It keeps the main loop clean and allows the complex logic for each state to be neatly organized in its own dedicated function. The actual transitions between states (e.g., from STRAIGHT to TURNING) are managed within these handler functions based on sensor-driven conditions.

#### 7.4.4. Sub-State Handler Functions: Implementing the Behavior

The logic for each sub-state is implemented in its own dedicated handler function, following a clear `_handle_*_sub_*()` naming convention. This modular approach makes the system easy to read, debug, and maintain. The roles of the primary handler functions are summarized below.

##### System Startup (`PREPARATION` State)

This initial state is responsible for all startup checks and initial setup before the robot begins its main tasks.

| Sub-State | Handler Function | Functionality |
| :--- | :--- | :--- |
| **`WAITING_FOR_CONTROLLER`**| `_handle_preparation_sub_waiting_for_controller()` | Waits for the low-level motor controller to become ready before proceeding. |
| **`INITIALIZING_CAMERA`** | `_handle_preparation_sub_initializing_camera()` | Moves the camera servos to their default starting positions. |
| **`DETERMINE_DIRECTION`** | `_handle_preparation_sub_determine_direction()` | Determines the course direction (CW/CCW) by analyzing LiDAR data from the parking spot. |

##### Unparking (`UNPARKING` State)

This group of functions manages the sequence of safely exiting the parking area and entering the main course.

| Sub-State | Handler Function | Functionality |
| :--- | :--- | :--- |
| **`PRE_UNPARKING_DETECTION`** | `_handle_unparking_sub_pre_unparking_detection()` | Scans the exit for obstacles and selects one of the four `UnparkingStrategy` patterns. |
| **`INITIAL_TURN`** | `_handle_unparking_sub_initial_turn()` | Executes the initial turn to enter the course, based on the selected strategy. |
| **`AVOIDANCE_REVERSE`** | `_handle_unparking_sub_avoidance_reverse()` | (CCW Close-Obstacle Strategy) Reverses to create space before making the turn. |

##### Straight Driving and Planning (`STRAIGHT` State)

This is the most complex state, responsible for wall-following, planning for the next segment, and executing all obstacle avoidance maneuvers.

| Sub-State | Handler Function | Functionality |
| :--- | :--- | :--- |
| **`ALIGN_WITH_OUTER_WALL`** <br> **`ALIGN_WITH_INNER_WALL`** | `_handle_straight_sub_align_with_outer_wall()` <br> `_handle_straight_sub_align_with_inner_wall()` | The default driving mode. Uses the PID controller to maintain a precise distance from the designated (outer or inner) wall. |
| **`PLAN_NEXT_AVOIDANCE`** | `_handle_straight_sub_plan_next_avoidance()` | Executes the "Move-and-Scan" routine at a corner to detect obstacles and generate the `avoidance_path_plan`. (1st lap only) |
| **`AVOID_OUTER_TURN_IN`** <br> **`AVOID_INNER_TURN_IN`** | `_handle_straight_sub_avoid_outer_turn_in()` <br> `_handle_straight_sub_avoid_inner_turn_in()` | Initiates an avoidance maneuver by steering sharply towards the opposite wall (inner or outer) to create space. |
| **`PRE_SCANNING_REVERSE`** | `_handle_straight_sub_pre_scanning_reverse()` | Reverses the robot to a safe distance before starting the `PLAN_NEXT_AVOIDANCE` scan. |

##### Cornering (`TURNING` State)

This state executes a precise, multi-step maneuver to navigate the 90-degree corners of the course.

| Sub-State | Handler Function | Functionality |
| :--- | :--- | :--- |
| **`POSITIONING_REVERSE`** | `_handle_turning_sub_positioning_reverse()` | Reverses the robot to a standardized starting position to ensure consistent turns. |
| **`APPROACH_CORNER`** | `_handle_turning_sub_approach_corner()` | Moves forward towards the corner until it reaches the optimal distance to begin the pivot turn. |
| **`EXECUTE_PIVOT_TURN`** | `_handle_turning_sub_execute_pivot_turn()` | Executes a high-agility, fixed-angle pivot turn to change the robot's heading by approximately 90 degrees. |
| **`FINALIZE_TURN`** | `_handle_turning_sub_finalize_turn()` | Updates the turn counter and transitions the main state back to `STRAIGHT`. |

##### Parking (`PARKING` State)

This state manages the entire end-of-mission sequence, from preparing for the final approach to executing the parallel parking maneuver.

| Sub-State | Handler Function | Functionality |
| :--- | :--- | :--- |
| **`PREPARE_PARKING`** | `_handle_parking_sub_prepare_parking()` | Analyzes the robot's final state (direction/lane) and selects the appropriate preparation strategy (U-turn, lane change, or direct proceed). |
| **`REORIENT_FOR_PARKING`**| `_handle_parking_sub_reorient_for_parking()` | (CW Strategy) Executes a multi-step U-turn to reverse the robot's direction. |
| **`LANE_CHANGE_FOR_PARKING`**|`_handle_parking_sub_lane_change_for_parking()` | (CCW/Inner Strategy) Executes a maneuver to move from the inner to the outer lane. |
| **`APPROACH_PARKING_START`**| `_handle_parking_sub_approach_parking_start()` | Precisely moves the robot to the exact starting position for the final parking maneuver, using a stability counter to ensure accuracy. |
| **`EXECUTE_PARKING_MANEUVER`**| `_handle_parking_sub_execute_parking_maneuver()`| Executes the final four-step parallel parking sequence (reverse-turn, reverse-straight, align-turn, final-adjust) to park the vehicle. |

##### Mission End (`FINISHED` State)
The `FINISHED` state is the simplest of all. Its handler, `_handle_state_finished()`, has only one job: to publish a zero-velocity command, bringing the robot to a complete and safe stop. It also calculates and logs the total run time.

*(Note: Some legacy states like `DETERMINE_COURSE` have been omitted for clarity as they are not used in the primary parking-start mode.)*

### 7.4.5. Core Algorithms: The Intelligence Behind the Action

Beyond the state machine structure, the robot's intelligent behavior is driven by a few core algorithms. These functions are called repeatedly from the various sub-state handlers to perform complex tasks like stable navigation and reliable sensing.

**The "Aha!" Moment & Solution:** Through experimentation, we discovered that even the black walls provide reliable readings if, and only if, the laser hits them at a **perfect 90-degree angle**. This led to the development of our core sensor fusion function, `get_distance_at_world_angle()`.

This function uses the robot's real-time orientation from the **IMU** to continuously calculate the *exact LiDAR angle needed to hit the wall perpendicularly*, regardless of the robot's own orientation. By dynamically selecting the perfect laser beam at every moment, we transformed a "fatal flaw" of the LiDAR into a reliable navigation tool.

<p align="center">
    Unparking Strategies
</p>

```python
# --- Pseudo Code for IMU + LiDAR Sensor Fusion ---
def get_distance_at_world_angle(world_angle_deg, current_yaw_deg, scan_data):
    """Gets a reliable wall distance by correcting for the robot's orientation."""

    # --- This is the core of the fusion logic ---
    # To hit a wall at a specific "world" angle (e.g., 90 degrees),
    # calculate the angle the LiDAR must look at relative to the robot's own front.
    robot_local_angle = world_angle_deg - current_yaw_deg
    
    # Find the specific laser beam in the 360-degree scan that matches this local angle.
    lidar_index = find_lidar_index_for_angle(robot_local_angle, scan_data)
    
    # Get the primary distance measurement from that single, perfect beam.
    distance = scan_data.ranges[lidar_index]

    # As a fallback, if the primary beam failed (e.g., hit a seam in the wall),
    # check its immediate neighbors to get a valid reading.
    if not is_valid(distance):
        distance = check_neighboring_beams(lidar_index, scan_data)

    return distance
```

### 7.5. Source Code: A Modular ROS 2 Ecosystem

Our software is not a single script, but a complete, modular robotics application built on the **ROS 2 framework**. The entire system is organized into a collection of specialized ROS 2 packages, each with a distinct responsibility. This "separation of concerns" is a key principle of modern software engineering, making our system robust, maintainable, and easy to extend.

The directory tree below shows the high-level structure of our ROS 2 workspace, which is composed of our core logic packages and the necessary hardware drivers.

```
src
├─ driver/ # Low-level hardware drivers for the motor controller
├─ imu/ # Node for the external IMU sensor
├─ international_final/ # Core logic for the main obstacle challenge
├─ japan_final/ # Logic adapted for the Japan Final (if different)
└─ peripherals/ # Launch files and configurations for camera, etc.
```

#### 7.5.1. The Brain: Core Navigation Logic

The central intelligence of our robot resides in the `international_final` package. This is where sensor data is processed, decisions are made via our state machine, and commands are issued. We have developed two primary navigator nodes for the different challenges.

*   **`obstacle_navigator_node.py` (Obstacle Challenge)**
    This is the heart of our system. It contains the full implementation of our Hierarchical State Machine, dynamic strategy selection, PID control, and all the algorithms described in the previous sections. The code is extensively commented to explain the purpose of each function and the logic behind our engineering decisions.
    > **[View Source Code: obstacle_navigator_node.py](src\WRO2025_FE\src\international_final\international_final\obstacle_navigator_node.py)**

*   **`open_navigator_node.py` (Open Challenge)**
    This is a simplified version of the navigator for the challenge without obstacles. It focuses purely on high-speed, stable wall-following and cornering.
    > **[View Source Code: open_navigator_node.py](src\WRO2025_FE\src\international_final\international_final\open_navigator_node.py)**

#### 7.5.2. Supporting Packages: Drivers and Interfaces

The "Brain" cannot function alone. It relies on a suite of supporting packages that act as the bridge to the physical hardware.

| Package Name | Role & Purpose |
| :--- | :--- |
| `ros_robot_controller` | This driver package interfaces directly with the Hiwonder motor controller board (STM32). It subscribes to `/controller/cmd_vel` and other command topics, translating high-level ROS commands into low-level motor and servo signals. |
| `ros_robot_controller_msgs`| Defines the **custom message and service types** (e.g., `SetPWMServoState`) that we created for communication between our logic node and the controller. This is crucial for controlling peripherals like the camera's pan-tilt servos. |
| `imu` | This package contains the node responsible for reading data from our external BNO055 IMU sensor and publishing the critical yaw (heading) data to the `/imu/yaw` topic. |
| `peripherals` | A utility package that contains the main **launch files** for starting the entire system, as well as configurations for hardware like the camera. |

#### 7.5.3. How to Run: Launch Files

To meet the goal of reproducibility, the entire system can be started with a single command using ROS 2 launch files. These files are the designated entry points that correctly start all the necessary nodes (drivers, logic, etc.) with the correct parameters.

Our main launch file, which brings the entire robot to life, can be found here:
> **[View Main Launch File: startup_manager.launch.py](src\WRO2025_FE\src\international_final\launch\startup_manager.launch.py)**

This modular and well-documented structure ensures that our work can be understood, verified, and reproduced by the judges.

### 7.6. Future Improvements

While we are proud of our current system, the engineering process is one of continuous improvement. Based on our testing and development experience, we have identified several key areas for future enhancement. This demonstrates our commitment to pushing the boundaries of what our robot can achieve.

| Area for Improvement | Current Status & Limitations | Proposed Future Enhancement |
| :--- | :--- | :--- |
| **State Machine Robustness** | Our state machine is currently implemented with a series of `if/elif` statements. While effective, it can become complex to manage as more states are added. | Transition to a formal state machine library (like `SMACH` for ROS 2). This would provide greater robustness, clearer state transition definitions, and better visualization tools. |
| **Localization Accuracy** | We currently rely on a turn counter and corner detection for localization. This can be prone to errors if a corner is missed or misidentified. | Implement a more advanced localization algorithm, such as an **Extended Kalman Filter (EKF)**, to fuse data from the IMU, wheel encoders, and LiDAR. This would provide a much more accurate and reliable estimate of the robot's position on the course at all times. |
| **Parameter Tuning** | Our many control parameters (e.g., PID gains, turning speeds) are currently tuned manually through extensive trial and error. This process is time-consuming and may not yield the absolute optimal values. | Develop a simulation environment (e.g., in Gazebo) to automate the tuning process. Using optimization algorithms or machine learning (Reinforcement Learning), we could automatically discover the best set of parameters for maximum speed and stability. |

These planned improvements show that our current design is not an endpoint, but a solid foundation upon which even more advanced and intelligent behaviors can be built.

---

## 8. Engineering Design & Manufacturing

### 8.1. Design Philosophy: From Kit to Custom Vehicle

Our journey in the WRO Future Engineers category began with the Hiwonder MentorPi A1 kit, which provided a solid foundation. However, we believe that true engineering lies not in assembling a kit, but in **reimagining and re-engineering** it to conquer specific challenges. Our philosophy was to transform the base vehicle into a highly specialized machine, meticulously optimized for the WRO course through our own design and manufacturing capabilities.

Every custom component on our robot is the answer to a specific problem we identified during testing. From redesigning the core drive system to comply with competition rules, to engineering sensor mounts for optimal data acquisition, our approach has been one of **purpose-driven design**.

This section details our key engineering decisions and showcases the custom-designed components that define our robot's unique performance. All parts were designed in SOLIDWORKS and manufactured using 3D printing, demonstrating a complete design-to-fabrication cycle. All design files, including source CAD files, printable `.stl` files, blueprints, and assembly diagrams, are available in our [`models`](models) directory to ensure full reproducibility.

### 8.2. Core System Redesign: A Custom Drive with a Mechanical Differential

#### 8.2.1. The Initial Challenge: Ensuring Rule Compliance

The stock MentorPi A1 chassis featured a dual-motor drive system for its rear wheels. This configuration, where two independent motors are controlled by software, constitutes an "electronic differential," which is explicitly **not permitted** under the WRO Future Engineers rules. Our first and most critical engineering challenge was to completely redesign the drive system to be **unambiguously compliant** with the regulations by implementing a purely mechanical solution.

#### 8.2.2. Our Solution: A Custom Drive with a Mechanical Differential

We replaced the dual-motor setup with a **single DC motor**. To distribute power to both wheels and allow them to rotate at different speeds during turns, we engineered a system that combines a **standard LEGO Technic differential gear set** for its proven reliability, with our own **custom-designed and 3D-printed gearbox housing and bevel gears** to integrate it seamlessly into our chassis.

<p align="center">
  Stock MentorPi A1 chassis with dual-motor drive
  Stock MentorPi A1 chassis with dual-motor drive
  <br>
  <em>The stock MentorPi A1 chassis, which features the original dual-motor drive system (left) that we replaced. Our custom single-motor differential assembly (a photo of which is in Section 5.2.2) was engineered to fit this frame while complying with competition rules. Image sourced from <a href="https://www.hiwonder.com/products/ackermann-steering-chassis?variant=40382428348503">Hiwonder's official product page</a>.</em>
</p>

### 8.3. Key Component Design & Manufacturing 

Beyond the core drive system, we designed and 3D-printed a suite of custom components to optimize our robot's performance, stability, and sensor integration. Each part was modeled in SOLIDWORKS with specific functional goals in mind, addressing challenges we discovered during testing and assembly. This section highlights the design rationale behind some of our most critical custom parts.

*(Note: Details regarding our custom-designed drivetrain and steering components, such as the gearbox and bevel gears, are covered in **Section 5: Mobility Management**.)*

#### 8.3.1. LiDAR Mount Assembly

**Objective:** To achieve comprehensive and accurate environmental data acquisition while minimizing the risk of physical interference.

**Design & Rationale:**
We engineered a multi-part mount assembly with two primary features. First, it positions the LiDAR at an optimal height and slightly forward, ensuring its lasers reliably capture both the course walls and obstacles for the highest quality data. This forward placement also enables the sensor to measure obstacles located diagonally behind the robot. Second, the mount supports the LiDAR from above, allowing it to be **installed in an inverted position**. This orientation reduces the risk of the mount itself colliding with obstacles.

This inverted mounting concept was inspired by the design of [**last year's Future Engineers world champion team**](https://github.com/MoCsabi/WRO2024-FE-StormsNGR), demonstrating our commitment to learning from and building upon the best practices in the WRO community.

<p align="center">
  Close-up of the custom LiDAR mount assembly
  <br>
  <em>A close-up view of our custom LiDAR mount assembly. The 3D-printed upper frame suspends the LiDAR in an inverted position for optimal data acquisition and collision avoidance.</em>
</p>

#### 8.3.2. Camera Tower Assembly

**Objective:** To elevate the camera for a clear, unobstructed view, while retaining its full range of motion.

**Design & Rationale:**
To ensure reliable obstacle detection, a high vantage point is essential. We designed a tall tower structure to lift the camera well above the chassis. This "bird's-eye" perspective prevents the robot's own frame from blocking the view, allowing our software to capture a complete image of the entire upcoming segment.

A key design requirement was to **fully preserve the 2-axis (pan and tilt) functionality** of the original MentorPi A1 camera system. Our custom mount seamlessly integrates with the stock servo motors, allowing the elevated camera to retain its ability to pan side-to-side for scanning and tilt up-and-down. This retained mobility is critical for our `PLAN_NEXT_AVOIDANCE` strategy, where the camera must precisely aim down the upcoming track segment. The tower itself is designed to be lightweight yet rigid to ensure a stable image, even while the servos are in motion.

<p align="center">
  The integrated sensor tower assembly
  <br>
  <em>Our integrated sensor tower. The custom 3D-printed structure elevates the camera for a clear "bird's-eye" view, while the LiDAR is mounted low and inverted beneath it for optimal wall detection.</em>
</p>

#### 8.3.3. Custom Main Chassis

**Objective:** To create a foundational platform perfectly tailored to our custom drive/steering systems and optimized component layout.

**Design & Rationale:**
As our custom-designed components evolved, we reached the limits of what the stock chassis could accommodate. To break through these limitations, we made the pivotal decision to **redesign the main chassis from the ground up**.

Our primary goal was to create a platform that would seamlessly integrate our redesigned drive and steering mechanisms. The new chassis was meticulously modeled in SOLIDWORKS to ensure optimal placement for every component, preventing any physical interference between the single drive motor, the differential gearbox, the steering servo, and the wheels during their full range of motion. This redesign provided us with the architectural freedom to perfect our component layout for improved stability and easier maintenance, marking the final step in the evolution of our vehicle from a modified kit to a truly custom robot.

<p align="center">
  Our custom 3D-printed main chassis
  <br>
  <em>Our final 3D-printed chassis, which provides dedicated mounting points for the battery (low center) and the IMU breadboard (rear), solving the packaging challenges of the previous generation.</em>
</p>

This section details our key engineering decisions and showcases the custom-designed components that define our robot's unique performance. All parts were designed in SOLIDWORKS and manufactured using 3D printing, demonstrating a complete design-to-fabrication cycle.

To ensure full reproducibility of our design, all engineering files are organized in our [`models`](models) directory as follows:

*   **[`models/custom_parts/`](models/custom_parts/):** Contains the CAD source files (`.SLDPRT`) and manufacturing blueprints (`.pdf`) for every part we designed and 3D-printed.
*   **[`models/commercial_parts/`](models/commercial_parts/):** Includes CAD models of the off-the-shelf components we integrated, such as motors and sensors.
*   **[`models/assemblies/`](models/assemblies/):** Provides the complete CAD assembly model of the robot, along with detailed assembly diagrams (`.pdf`) that show how all custom and commercial parts fit together.

This structured approach ensures that another team can effortlessly reproduce our entire mechanical design from scratch.

<p align="center">
  Full Robot CAD Assembly
  <br>
  <em>A CAD render of the full robot assembly, showcasing the integration of our custom 3D-printed parts with the commercial components.</em>
</p>

### 8.4. Design Evolution: A Visual History

Our final robot design is not the result of a single brilliant idea, but of a rigorous **iterative development process**. We went through multiple generations of prototypes, with each version addressing the weaknesses of its predecessor. This cycle of **design, build, test, and improve** was fundamental to achieving the high level of performance and reliability our robot demonstrates today.

This section provides a visual timeline of our robot's key evolutionary stages, from the initial stock kit to our final custom-engineered vehicle.

#### 8.4.1. Generation 1: The Stock Platform

Our starting point was the unmodified MentorPi A1 kit. Early tests with this platform were crucial for understanding the basic dynamics of the vehicle and for identifying its inherent limitations. We quickly discovered several critical issues that needed to be addressed:

*   **Non-Compliant Drive System:** The dual-motor drive constituted a rule-breaking "electronic differential."
*   **Restrictive Steering:** The stock steering mechanism had a very large turning radius, making it unsuitable for precise maneuvers.
*   **Suboptimal Sensor Placement:** The LiDAR was mounted too high to accurately detect low-profile course walls, while the camera was mounted too low.
*   **Inadequate IMU Accuracy:** The onboard IMU lacked the precision and stability required for our IMU-fused navigation algorithms.

These foundational problems made it clear that a simple modification would not be enough; a significant re-engineering effort was required.

<p align="center">
  Generation 1: The stock MentorPi A1 platform
  Ackermann steering mechanism of the stock chassis
  <br>
  <em><b>Generation 1: The stock MentorPi A1 platform.</b><br>
  Left: The initial assembled kit. Right: The standard Ackermann steering structure, which had a limited turning angle. (Right image sourced from <a href="https://www.hiwonder.com/products/ackermann-steering-chassis?variant=40382428348503">Hiwonder</a>).<br>
  Early tests with this version revealed fundamental limitations in its drive system, steering agility, and sensor layout.</em>
</p>

#### 8.4.2. Generation 2: The First Custom Drive System

This generation represents our first major engineering leap to address the core issues of the stock platform. Our primary focus was to achieve rule compliance and begin optimizing the sensor layout.

*   **Drive System Overhaul:** We replaced the non-compliant dual-motor setup with our **custom single-motor mechanical differential drive**. This fundamental change, detailed in Section 8.2, brought our vehicle into full compliance with WRO rules.
*   **Initial Sensor Mounts:** We introduced the first versions of our custom **LiDAR and camera mounts**. The LiDAR was lowered to improve wall detection, and the camera was elevated to gain a better perspective.
*   **External IMU Integration:** The low-precision onboard IMU was replaced with the high-accuracy **BNO055 external IMU**, enabling our robust IMU-fused navigation.

While this version was a significant improvement, testing revealed a new bottleneck: the stock chassis itself. It physically limited the potential of our new steering geometry and prevented an ideal layout for our custom gearbox and other components. This led us to the final stage of our evolution.

<p align="center">
  Generation 2: Overall view with initial custom parts
  Close-up of the first custom differential drive
  <br>
  <em><b>Generation 2: The first major modification.</b><br>
  Left: The overall vehicle with initial custom sensor mounts. Right: A close-up of our first-generation custom differential drive, which achieved rule compliance.<br>
  This version, while functional, highlighted the physical limitations of the stock chassis for further optimization.</em>
</p>

#### 8.4.3. Generation 3: The First Custom Chassis

This generation marked our transition toward a truly custom vehicle. To overcome the physical limitations of the stock chassis identified in Gen 2, we designed and 3D-printed our **first iteration of a fully custom chassis**.

*   **Custom Chassis Integration:** The new chassis was our first attempt at a ground-up design, created to better accommodate our single-motor drive system and to provide the architectural freedom needed for a radically new steering geometry.
*   **Path to Agility:** This platform enabled the initial implementation of our innovative vertical servo layout. While it did not yet achieve our final performance target, this redesign **significantly improved the steering angle** compared to the stock version and proved that a dramatically smaller turning radius was achievable.

However, this prototype also revealed several key areas for improvement:
*   **Chassis Width:** The vehicle's overall width was **close to the 20 cm limit**, leaving a dangerously small margin for error during parking.
*   **Suboptimal Component Layout:** The mounting position for the breadboard (holding the IMU) was an afterthought, and there was no dedicated, secure location for the battery.

The successes and shortcomings of this generation provided the critical data needed to design our final, fully optimized vehicle.

<p align="center">
  Generation 3: Overall view of the first custom chassis
  Close-up of the innovative steering geometry
  <br>
  <em><b>Generation 3: The first custom chassis.</b><br>
  Left: The first fully custom-designed and printed chassis. Right: A close-up of the innovative vertical servo layout, which proved a smaller turning radius was achievable.<br>
  This prototype successfully validated our design direction but also revealed new challenges in component packaging and overall width.</em>
</p>

#### 8.4.4. Generation 4: The Final Integrated Vehicle

This is the current, competition-ready version of our robot, representing the culmination of our iterative design process. Leveraging the insights gained from the previous generation, we performed a final series of targeted redesigns to create a fully optimized and integrated vehicle.

*   **Optimized Chassis and Component Layout:** We designed a new, slightly narrower chassis that provides a greater margin for error during parking. This final chassis includes dedicated, secure mounting points for all components, including a purpose-built battery holder and a stable platform for the IMU's breadboard, resulting in a cleaner and more robust assembly.
*   **Achieved Ultimate Agility:** With the perfected chassis providing the necessary space, we finalized our steering geometry. This ultimate version achieves our target **minimum turning radius of just 15 cm**, granting our robot the exceptional agility required for all competition maneuvers.
*   **Integrated Suspension System:** This final design also fully realizes our **integrated monoshock suspension system** (as detailed in Section 5.2), maximizing traction and stability during high-speed runs.

This final generation is not just a collection of parts, but a single, cohesive system where every component has been custom-designed to work in harmony.

<p align="center">
  Generation 4: The final integrated vehicle
  Close-up of the final monoshock differential system
  <br>
  <em><b>Generation 4: The final integrated vehicle.</b><br>
  Left: The competition-ready robot, featuring an optimized, narrower chassis. Right: The perfected monoshock differential system, which integrates propulsion, differential action, and suspension.<br>
  This final form represents the culmination of our iterative engineering process, achieving all our performance goals.</em>
</p>

## 9. Performance Videos

This section provides video evidence of our robot's performance, demonstrating the successful implementation of all the strategies and designs discussed in this document. The videos show complete runs for each of the main challenges.

---

### 9.1. Obstacle Challenge

This video demonstrates our robot navigating the complex obstacle course. Key moments, such as the proactive corner scanning, dynamic turning strategies, and smooth two-phase avoidance maneuvers, are highlighted.

> **[Click to watch the Obstacle Challenge video on YouTube](https://youtu.be/YpugnEih1NA)**

<a href="https://youtu.be/YpugnEih1NA">
  <p align="center">
    Obstacle Challenge Video Thumbnail
  </p>
</a>

---

### 9.2. Open Challenge

This video showcases the robot's pure speed and cornering ability on the course without obstacles. It highlights the stability of our PID wall-following algorithm and the efficiency of our chassis and drive system at high speed.

> **[Click to watch the Open Challenge video on YouTube](https://youtu.be/kJocLs0_ztE)**

<a href="https://youtu.be/kJocLs0_ztE">
  <p align="center">
    Open Challenge Video Thumbnail
  </p>
</a>

---

## 10. References

This project was built upon the shoulders of giants. This section provides links to the key official documentation, product pages, and community resources that were essential to our development process.

### Official Rules & Frameworks
*   **[WRO 2025 Future Engineers - General Rules](https://wro-association.org/wp-content/uploads/WRO-2025-Future-Engineers-Self-Driving-Cars-General-Rules.pdf)**: The official rulebook that governed all aspects of our design and strategy.
*   **[ROS 2 Documentation](https://docs.ros.org/)**: The official documentation for the Robot Operating System 2, the core framework of our software.

### Key Hardware Components & Datasheets
*   **[Hiwonder MentorPi A1 Robotic Kit](https://www.hiwonder.com/products/mentorpi-a1-monocular-camera-version?variant=41370001244247)**: The base platform for our robot, including the chassis, camera, and several motors.
*   **[Hiwonder RRC Lite Controller](https://www.hiwonder.com/products/rrc-lite)**: The central interface board for power management and low-level control.
*   **[Raspberry Pi 5](https://www.raspberrypi.com/products/raspberry-pi-5/)**: The main single-board computer (SBC) that runs our ROS 2 navigation node.
*   **[STL-19P D500 LiDAR](https://www.hiwonder.com/products/ld19-d300-lidar?_pos=1&_sid=6968f314c&_ss=r)**: The primary 360° distance sensor for environmental mapping.
*   **[BNO055 9-Axis IMU](https://akizukidenshi.com/catalog/g/g116996/)**: The external Inertial Measurement Unit used for precise orientation tracking.

### Key Software & Libraries
*   **[SOLIDWORKS](https://www.solidworks.com/)**: The CAD software used to design all our custom 3D-printed parts.
*   **[OpenCV Library](https://opencv.org/)**: The open-source computer vision library used for obstacle color detection.
*   **[Draw.io (Diagrams.net)](https://app.diagrams.net/)**: The tool used to create the diagrams and flowcharts in this document.

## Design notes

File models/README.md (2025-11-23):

# 3D Models and Engineering Files

This directory contains all engineering files for our robot's mechanical design.

## Directory Structure

*   [`custom_parts/`](./custom_parts/): CAD files (`.SLDPRT`) and blueprints (`.pdf`) for parts we designed.
*   [`commercial_parts/`](./commercial_parts/): CAD models of off-the-shelf components.
*   [`assemblies/`](./assemblies/): The complete robot assembly model and diagrams.

---

### Related Documentation

The design philosophy, development story, and detailed explanations for these components can be found in the main project README at the following sections:

- **[Section 5: Mobility Management](../../README.md#5-mobility-management)** (for drivetrain and steering components like the gearbox and linkages)
- **[Section 8: Engineering Design & Manufacturing](../../README.md#8-engineering-design--manufacturing)** (for a comprehensive overview of all custom parts)

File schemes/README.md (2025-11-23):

# Schemes and Diagrams

This directory contains all diagrams that visually explain our robot's architecture and logic.

## Contents

*   **`ackermann_kinematics.png`**: Illustrates the kinematic model.
*   **`ros2_node_diagram.png`**: Shows the ROS 2 node communication flow.
*   **`state_flowchart.png`**: Provides a high-level overview of the state machine.
*   **`wiring_diagram.png`**: Details the robot's electrical connections.
*   ... *(and other diagrams)*

---

### Related Documentation

These diagrams are embedded within the main project README. For detailed context and explanations for each diagram, please refer to the following sections:

- **Wiring Diagram:** [Section 6.3. Wiring Diagram](../../README.md#63-wiring-diagram)
- **State Flowchart & ROS 2 Diagram:** [Section 7.1 & 7.2](../../README.md#71-overall-strategy-a-hierarchical-state-machine)
- **Kinematic Model:** [Section 5.3. Steering Mechanism](../../README.md#kinematic-model)

# System Schematics and Design Diagrams

This directory contains all the schematics, flowcharts, and diagrams that visually represent the design and logic of our robot. These diagrams are essential companions to the main project `README.md` and provide a deeper insight into our engineering process.

---

## Main Wiring Diagram

This is the master schematic illustrating the complete electrical connections between all major components of our robot. This centralized wiring, managed by the RRC Lite Controller, simplifies the overall structure and enhances reliability.

> For a detailed explanation of the power system and sensor suite, see [**Section 6: Power and Sense Management**](../../README.md#6-power-and-sense-management) in the main documentation.

<p align="center">
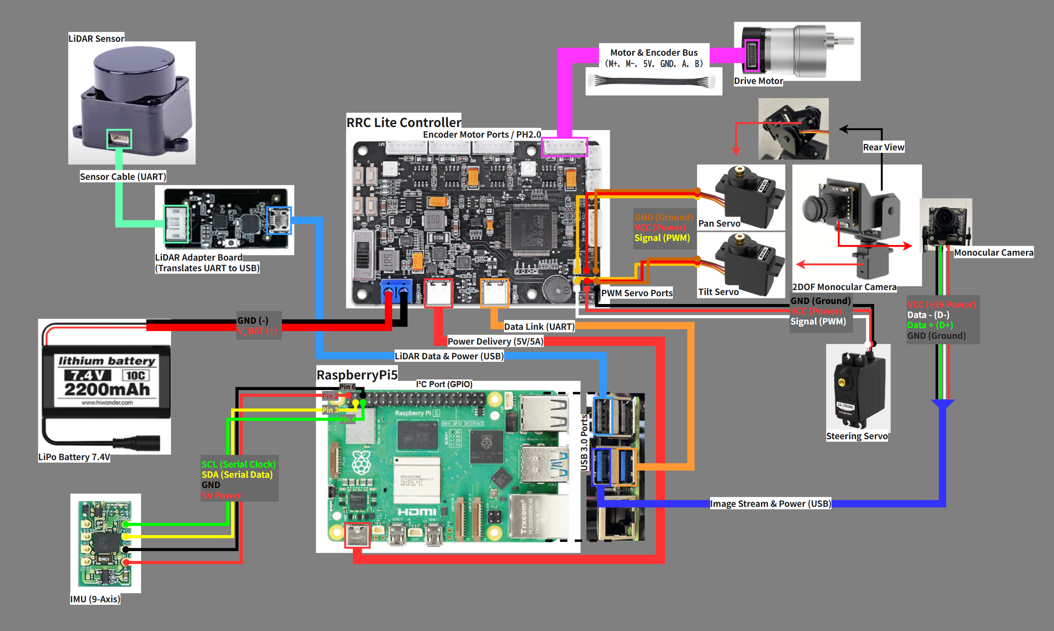
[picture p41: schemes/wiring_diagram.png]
Main Wiring Diagram
  
  <br>
  <em>The complete electrical schematic showing connections between all major hardware components.</em>
</p>

---

## System Architecture & Logic Flow

These diagrams illustrate the software architecture and the strategic logic that governs the robot's behavior. The State Machine Flowchart provides a high-level overview of the robot's operational states, while the Node Architecture diagram shows how data flows between different software modules in ROS 2.

> For a detailed explanation of our software architecture and state machine, see [**Section 7.1 & 7.2**](../../README.md#71-overall-strategy-a-hierarchical-state-machine) in the main documentation.

<p align="center">
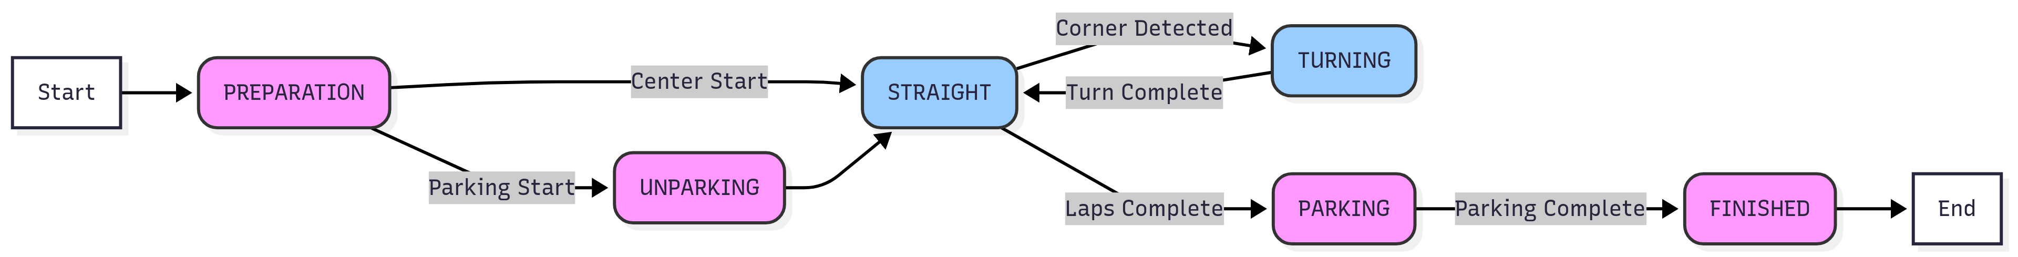
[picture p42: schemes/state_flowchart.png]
State Machine Flowchart
  
  <br>
  <em>A high-level flowchart of the robot's main operational states, from Preparation to Finished.</em>
</p>
<p align="center">
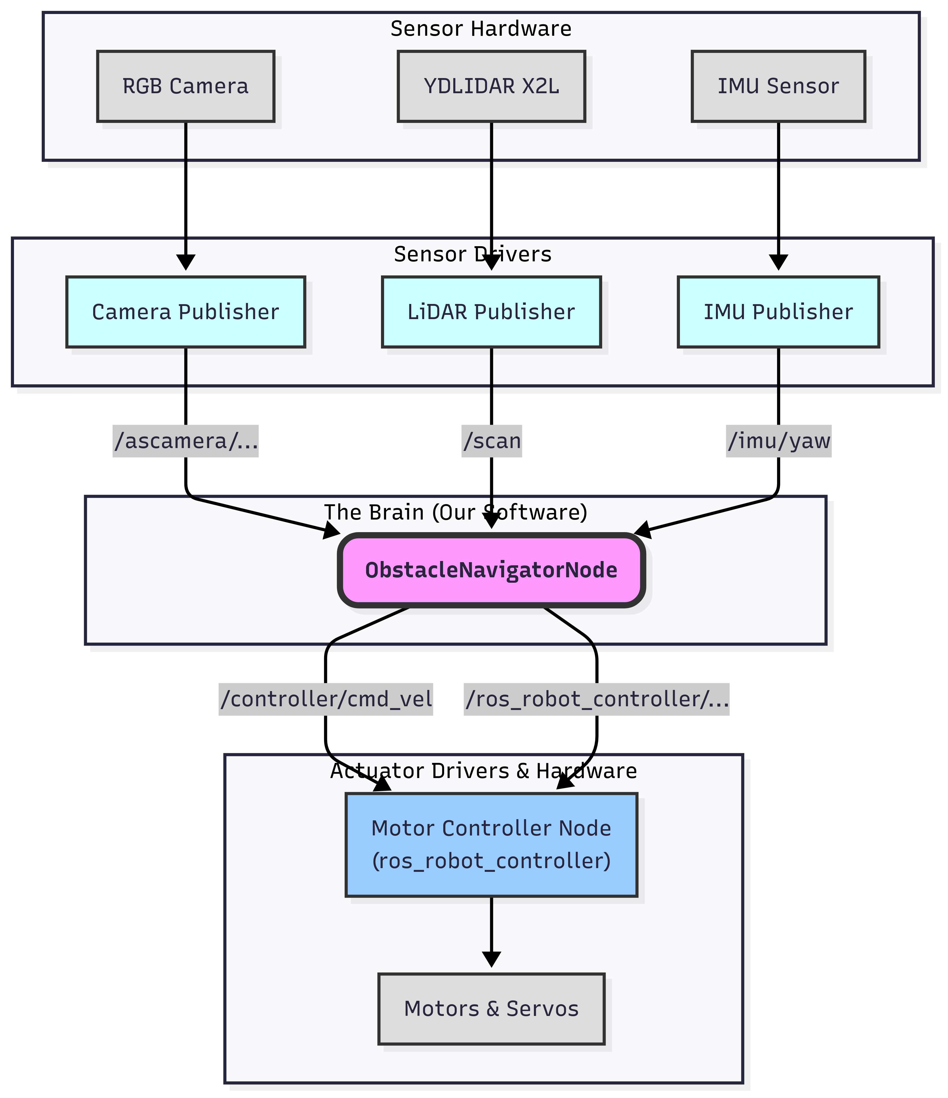
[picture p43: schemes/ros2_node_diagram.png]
ROS 2 Node Architecture
  
  <br>
  <em>Illustrates the flow of data between our custom ROS 2 nodes and hardware drivers.</em>
</p>

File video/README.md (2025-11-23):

# Performance Videos

This directory contains the video files demonstrating our robot's performance.

---

### Related Documentation

For direct viewing links, thumbnails, and descriptions of these videos, please see **[Section 9: Performance Videos](../../README.md#9-performance-videos)** in the main project README.

### Obstacle Challenge

This video demonstrates our robot navigating the complex obstacle course. Key moments, such as the proactive corner scanning, dynamic turning strategies, and smooth two-phase avoidance maneuvers, are highlighted.

> **[Click to watch the Obstacle Challenge video on YouTube](https://youtu.be/YpugnEih1NA)**

---

### Open Challenge

This video showcases the robot's pure speed and cornering ability on the course without obstacles. It highlights the stability of our PID wall-following algorithm and the efficiency of our chassis and drive system at high speed.

> **[Click to watch the Open Challenge video on YouTube](https://youtu.be/kJocLs0_ztE)**

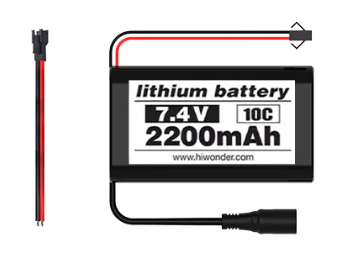
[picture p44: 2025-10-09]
assets/lopo_battery_specs.png

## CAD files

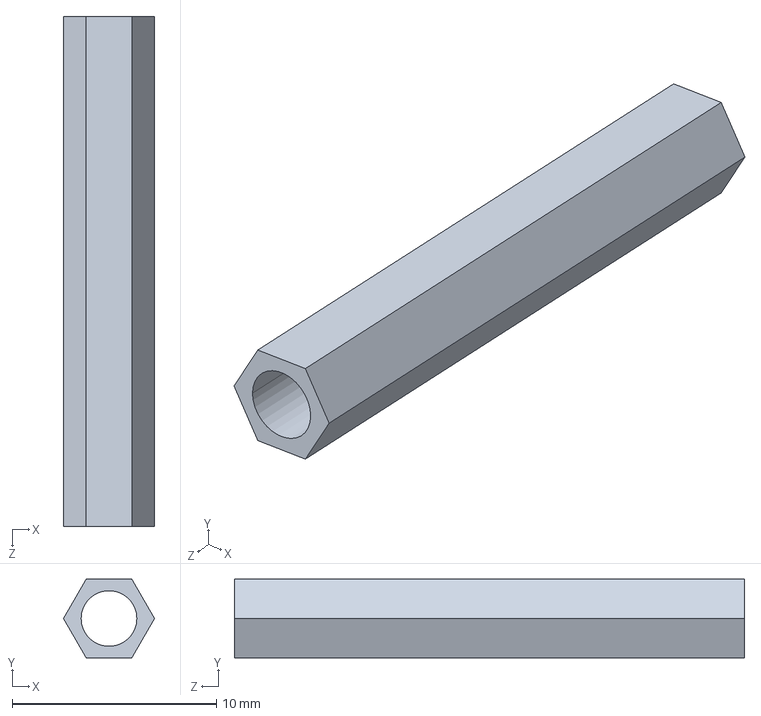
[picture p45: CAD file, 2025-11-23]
models/commercial_parts/spacer_steering_assy.SLDPRT
4.47 x 3.87 x 25.0 mm

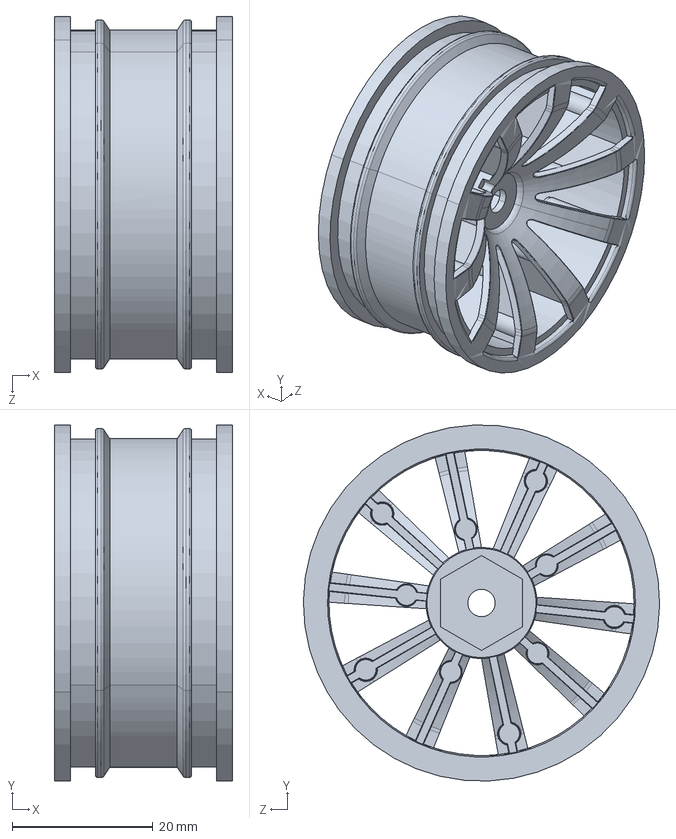
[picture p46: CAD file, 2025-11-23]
models/commercial_parts/wheel.SLDPRT
25.4 x 50.7 x 50.7 mm

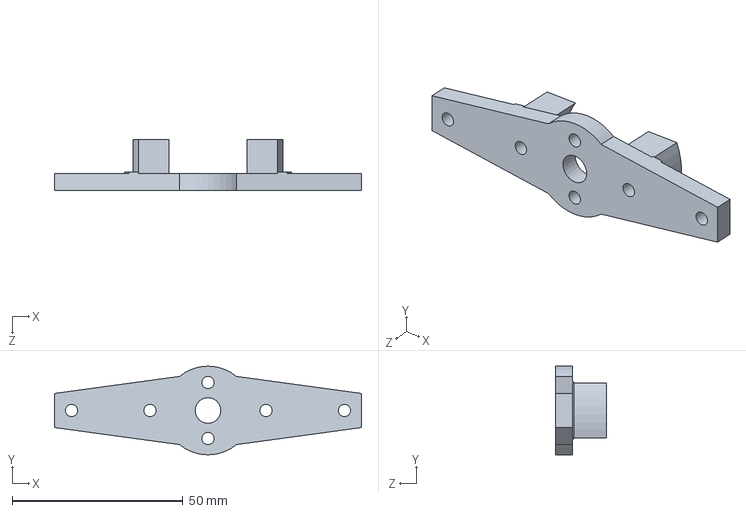
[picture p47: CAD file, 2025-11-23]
models/custom_parts/cad_files/gearbox_frontend.SLDPRT
90.0 x 26.0 x 15.0 mm

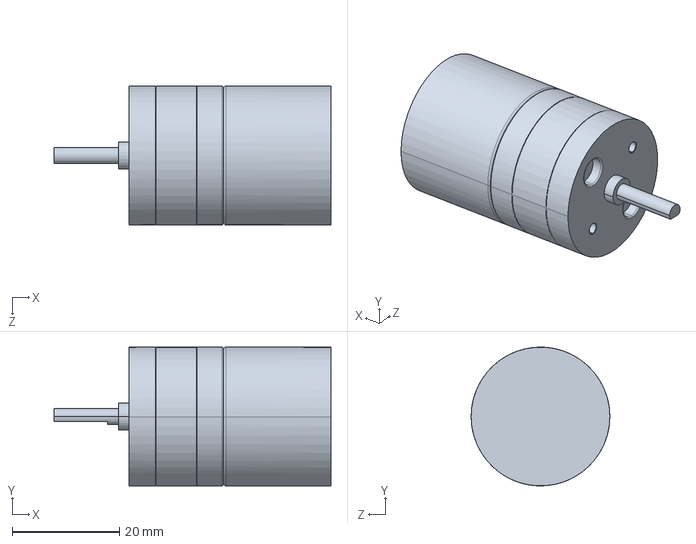
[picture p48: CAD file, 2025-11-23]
models/commercial_parts/motor.SLDPRT
51.7 x 25.9 x 25.9 mm

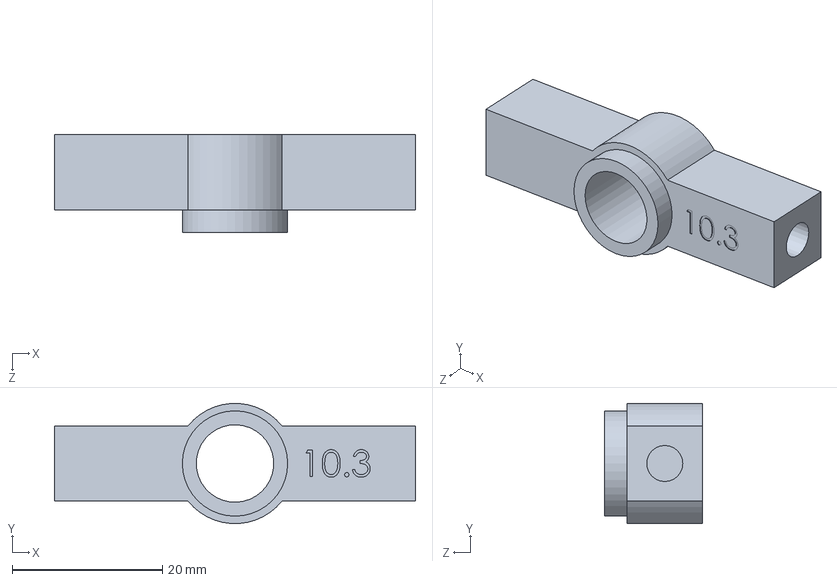
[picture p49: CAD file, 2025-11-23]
models/custom_parts/cad_files/gearbox_bearing_outer.SLDPRT
48.0 x 16.0 x 13.0 mm

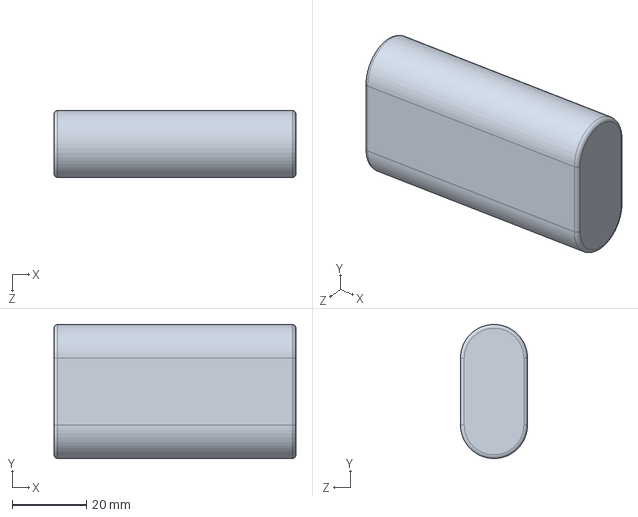
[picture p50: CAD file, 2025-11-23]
models/commercial_parts/battery.SLDPRT
65.0 x 36.0 x 18.0 mm

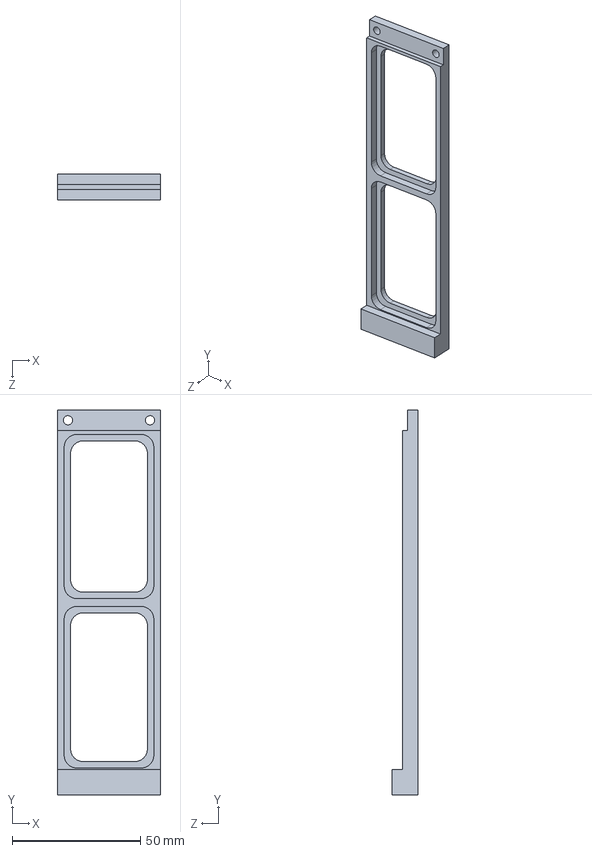
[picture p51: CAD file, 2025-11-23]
models/custom_parts/cad_files/camera_mount_side.SLDPRT
40.0 x 150.0 x 10.0 mm

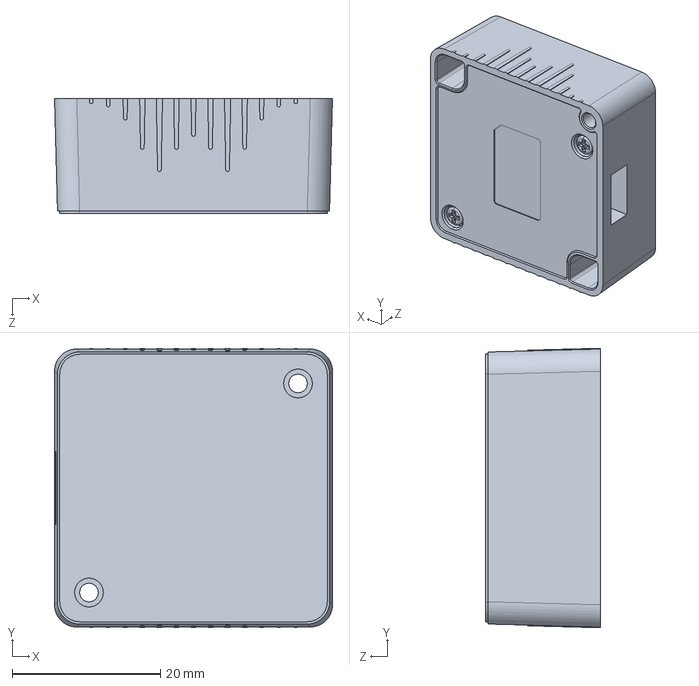
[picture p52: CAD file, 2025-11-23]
models/commercial_parts/LiDAR2.SLDPRT
37.5 x 37.7 x 15.5 mm

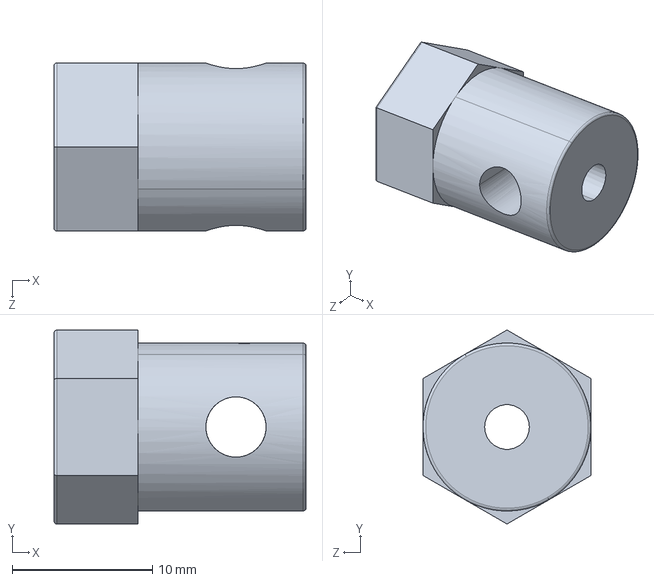
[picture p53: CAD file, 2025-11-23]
models/custom_parts/cad_files/front_hub.SLDPRT
18.0 x 13.9 x 12.0 mm

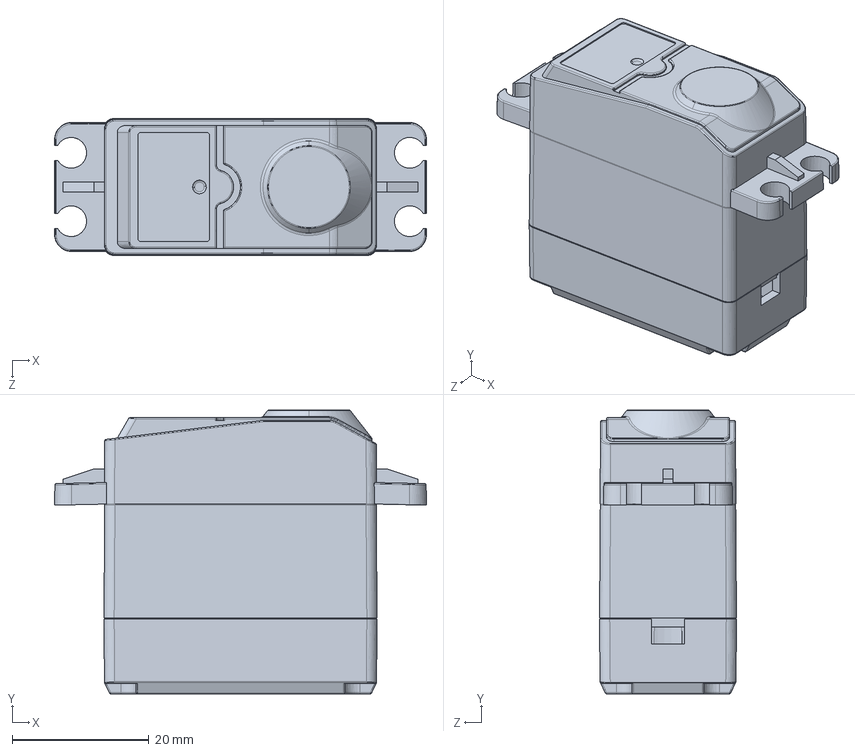
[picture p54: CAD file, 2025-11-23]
models/commercial_parts/servo.SLDPRT
54.4 x 41.5 x 20.0 mm

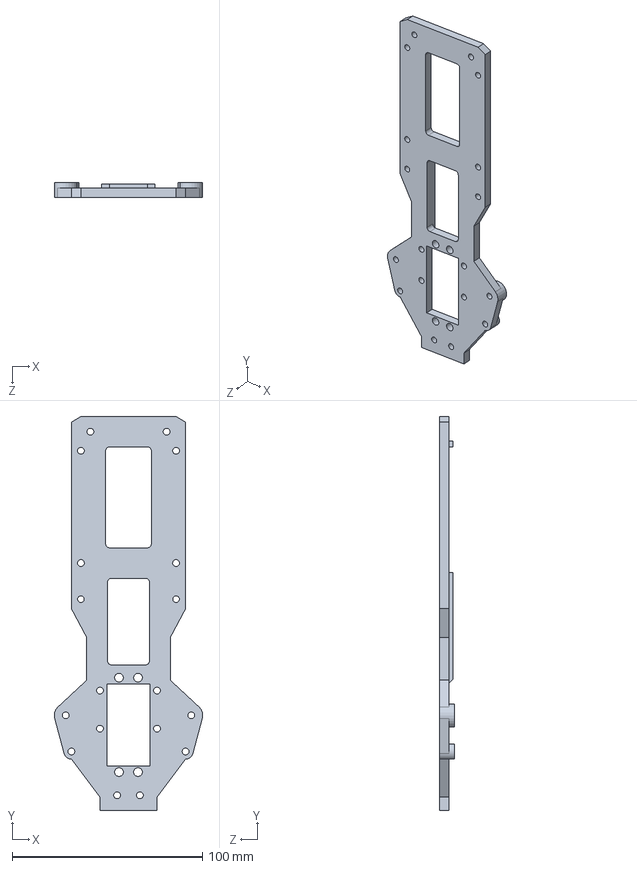
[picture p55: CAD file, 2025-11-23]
models/custom_parts/cad_files/chassis.SLDPRT
78.0 x 207.0 x 7.80 mm

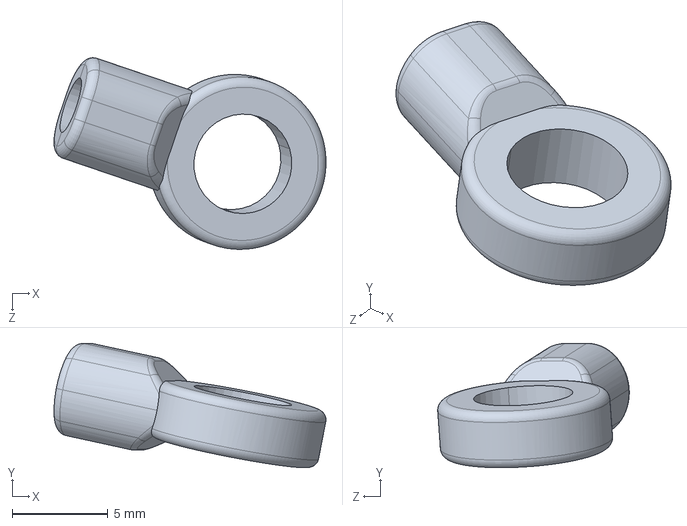
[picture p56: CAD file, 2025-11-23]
models/commercial_parts/rodend.SLDPRT
14.2 x 6.48 x 9.99 mm

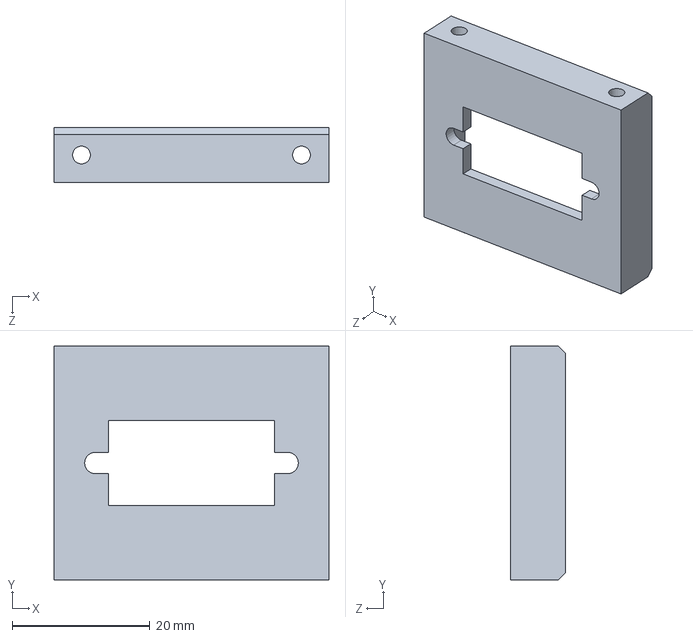
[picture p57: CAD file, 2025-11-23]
models/custom_parts/cad_files/camera_mount_upper.SLDPRT
40.0 x 34.0 x 8.00 mm

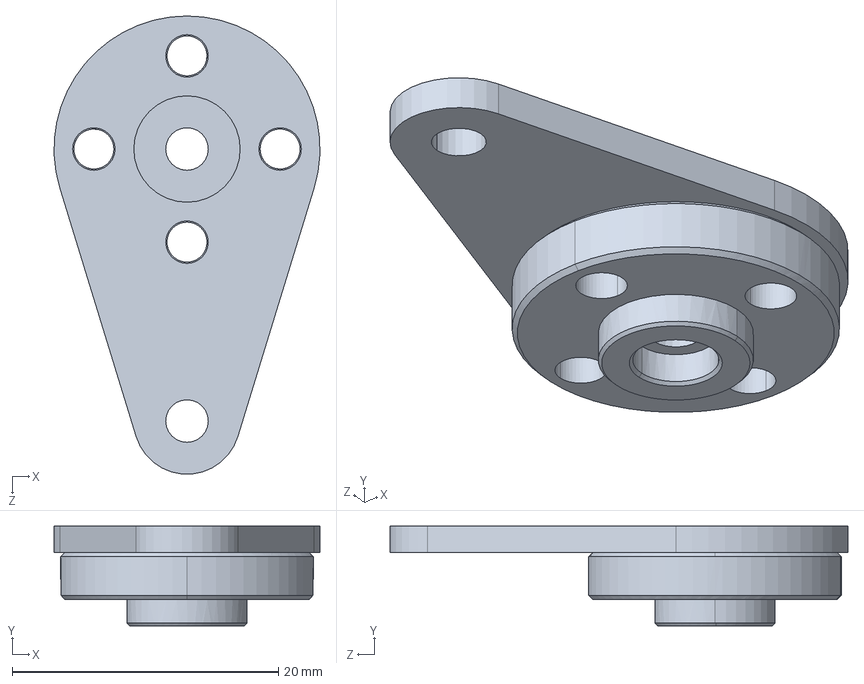
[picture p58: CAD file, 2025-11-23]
models/commercial_parts/servo-horn.SLDPRT
20.0 x 7.50 x 34.4 mm

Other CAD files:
models/assemblies/Assem1.SLDASM
models/custom_parts/cad_files/Bevel_Gear.SLDPRT
models/commercial_parts/rod-B.SLDPRT
models/custom_parts/cad_files/breadboard_mount.SLDPRT
models/commercial_parts/LiDAR.SLDPRT
models/commercial_parts/arm-L.SLDPRT
models/commercial_parts/arm-R.SLDPRT
models/commercial_parts/rod-A.SLDPRT
models/commercial_parts/spacer_board.SLDPRT
models/commercial_parts/tire.SLDPRT
models/custom_parts/cad_files/LiDAR_mount_back.SLDPRT
models/custom_parts/cad_files/LiDAR_mount_upper.SLDPRT
models/custom_parts/cad_files/battery_holder_front.SLDPRT
models/custom_parts/cad_files/battery_holder_rear.SLDPRT
models/custom_parts/cad_files/gearbox_bearing_inner.SLDPRT
models/custom_parts/cad_files/gearbox_mount_front.SLDPRT
models/custom_parts/cad_files/gearbox_mount_rear.SLDPRT
models/custom_parts/cad_files/gearbox_rearend.SLDPRT
models/custom_parts/cad_files/hub_rear.SLDPRT
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

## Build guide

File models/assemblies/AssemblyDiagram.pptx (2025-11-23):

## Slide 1

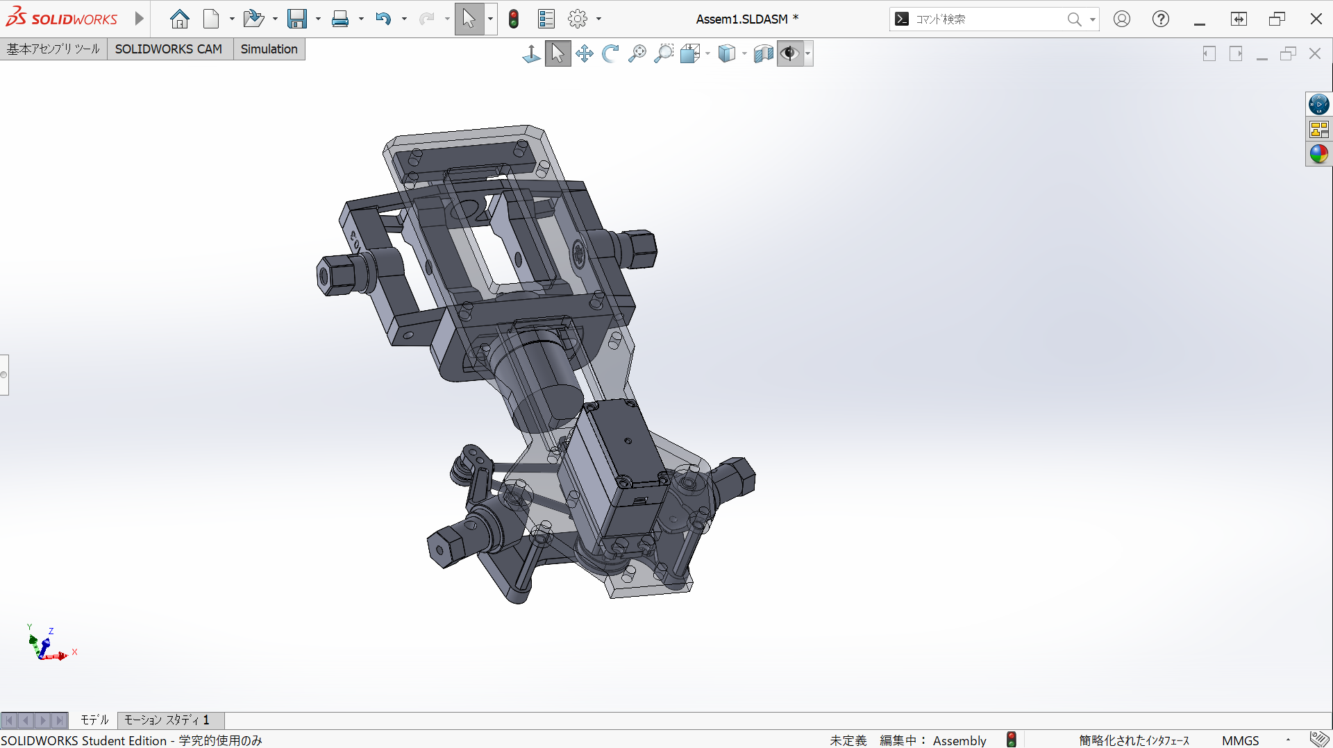
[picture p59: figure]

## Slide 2

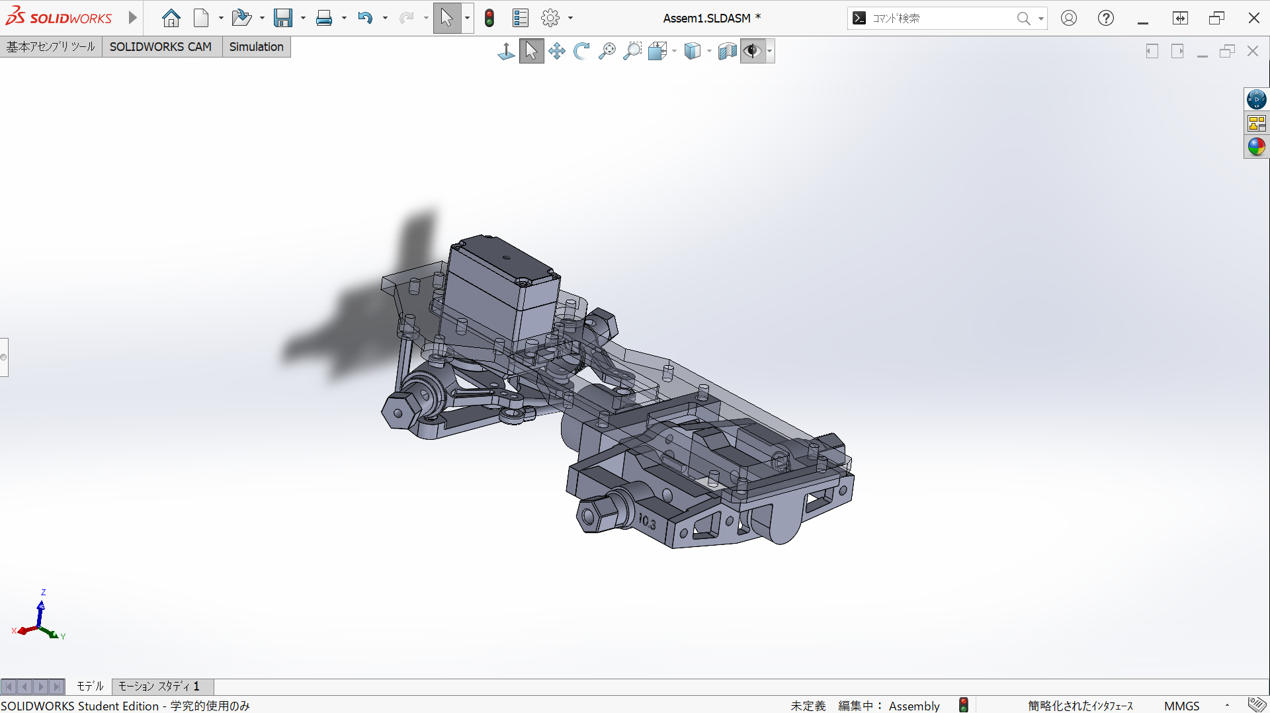
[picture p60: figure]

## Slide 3

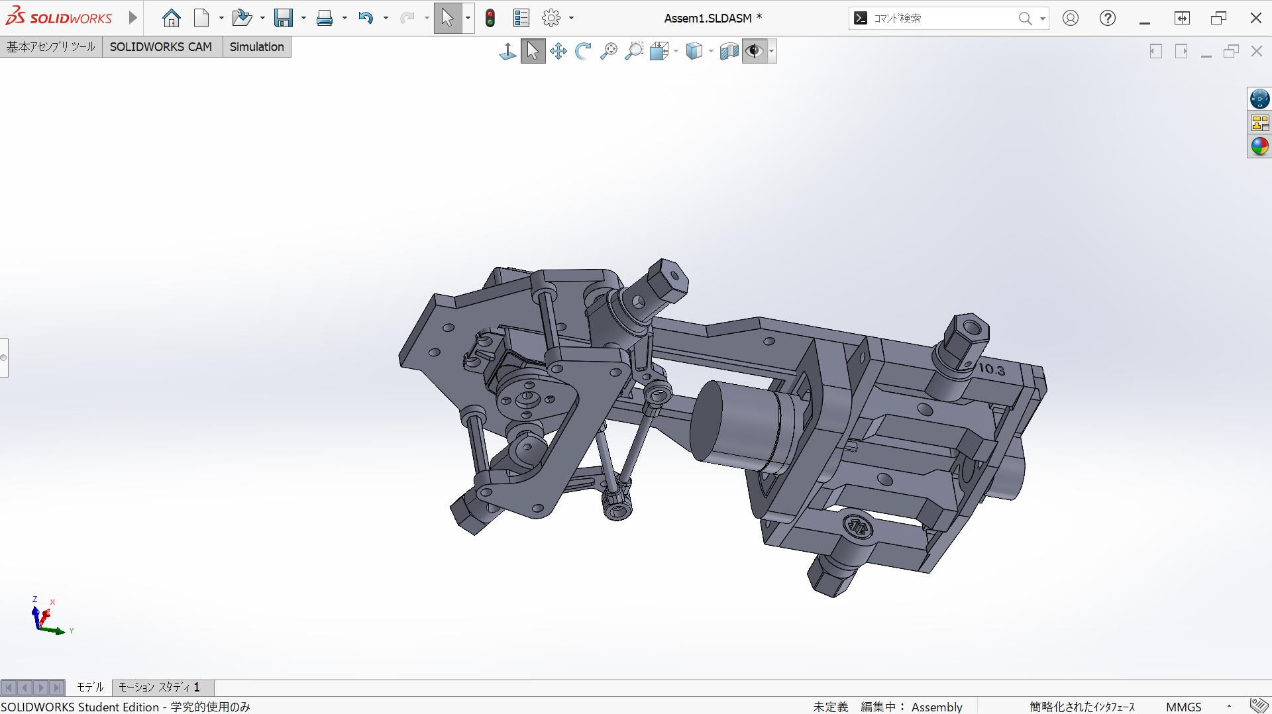
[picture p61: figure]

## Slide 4

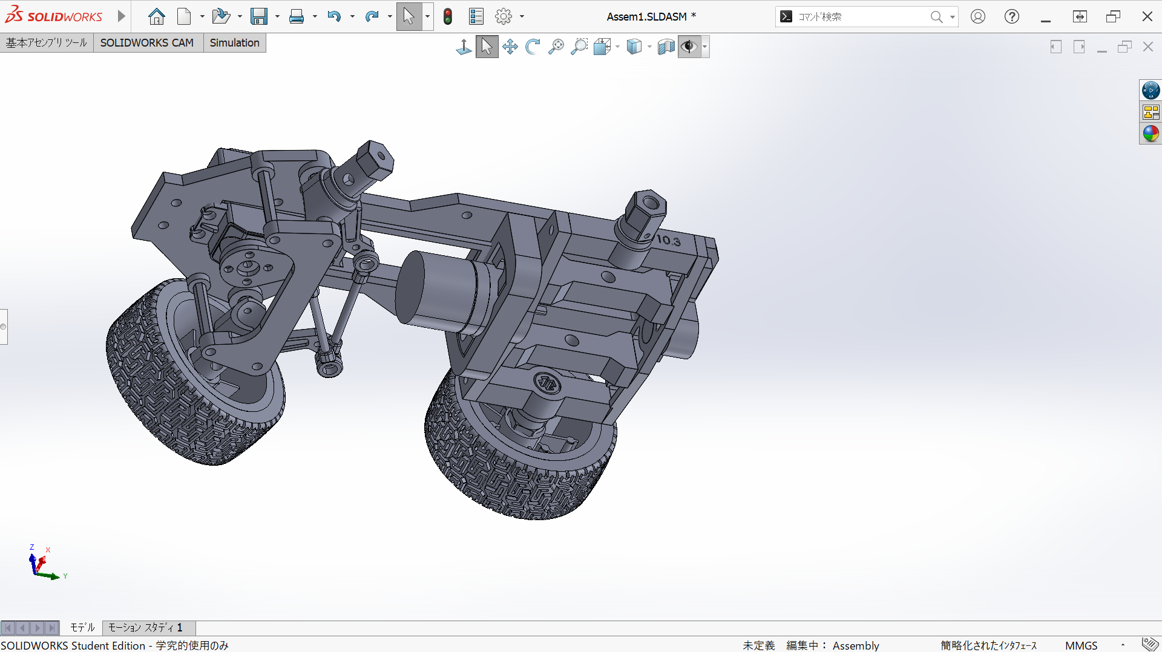
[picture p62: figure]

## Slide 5

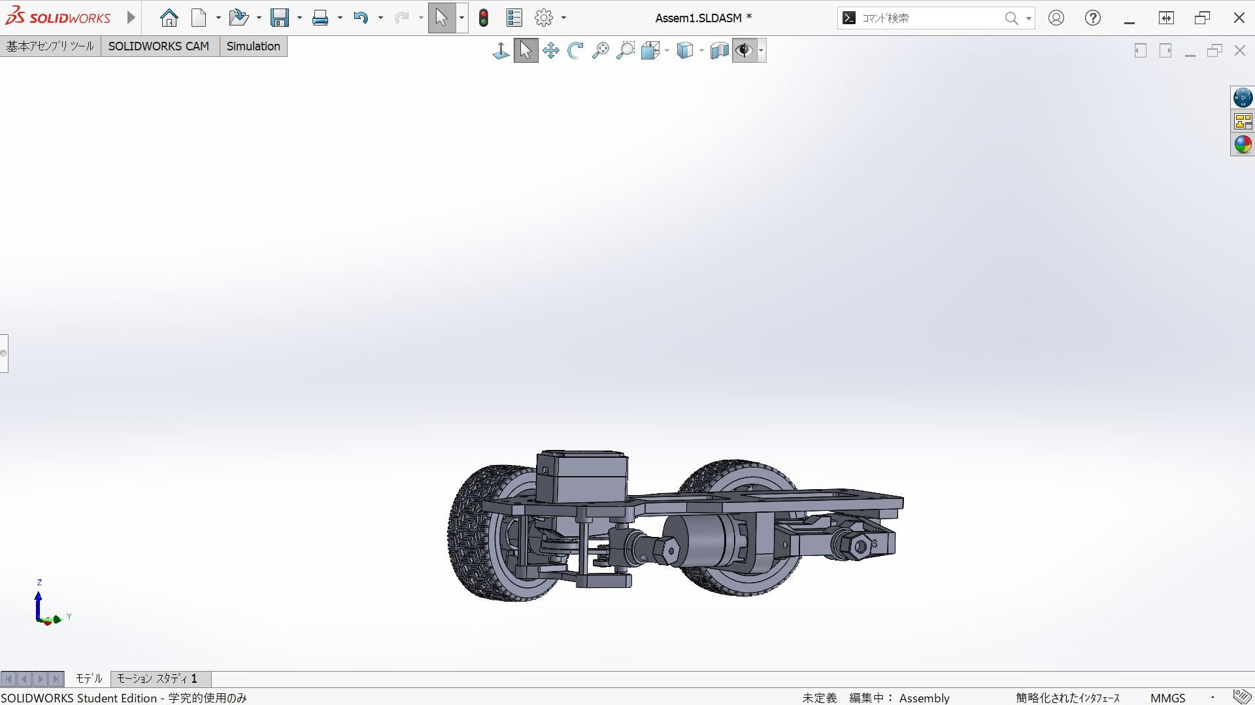
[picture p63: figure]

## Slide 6

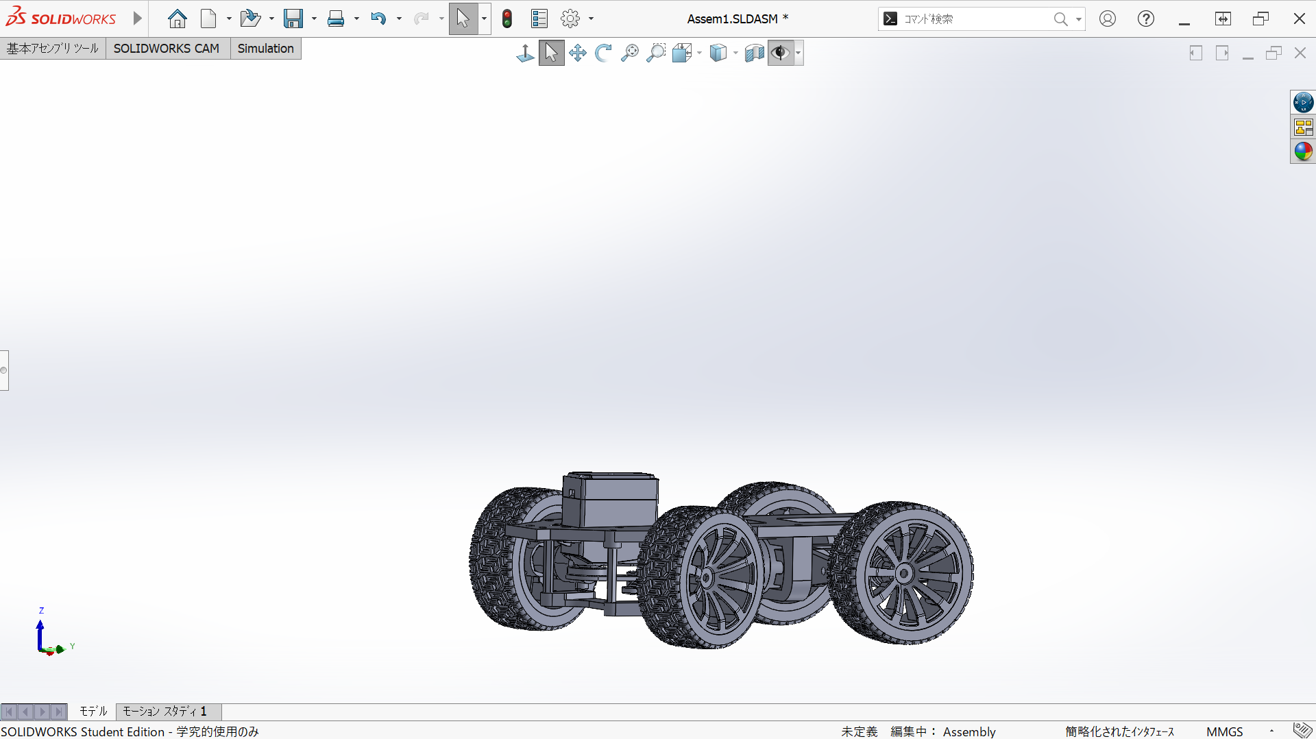
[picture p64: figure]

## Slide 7

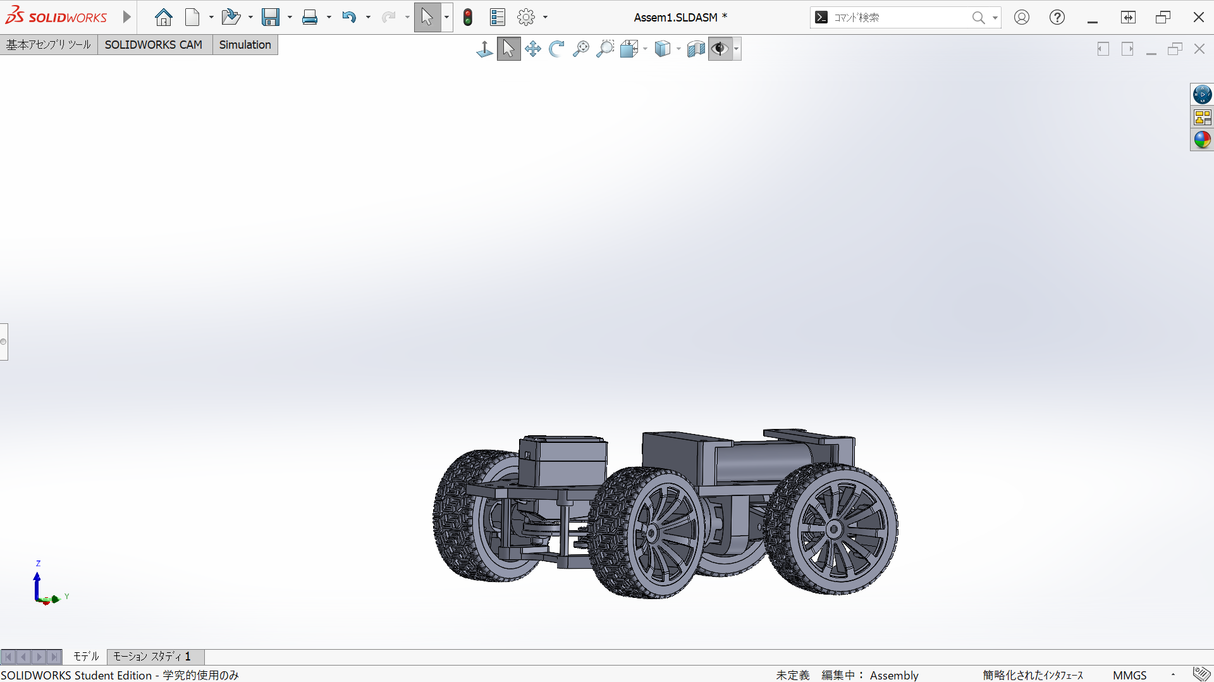
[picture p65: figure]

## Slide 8

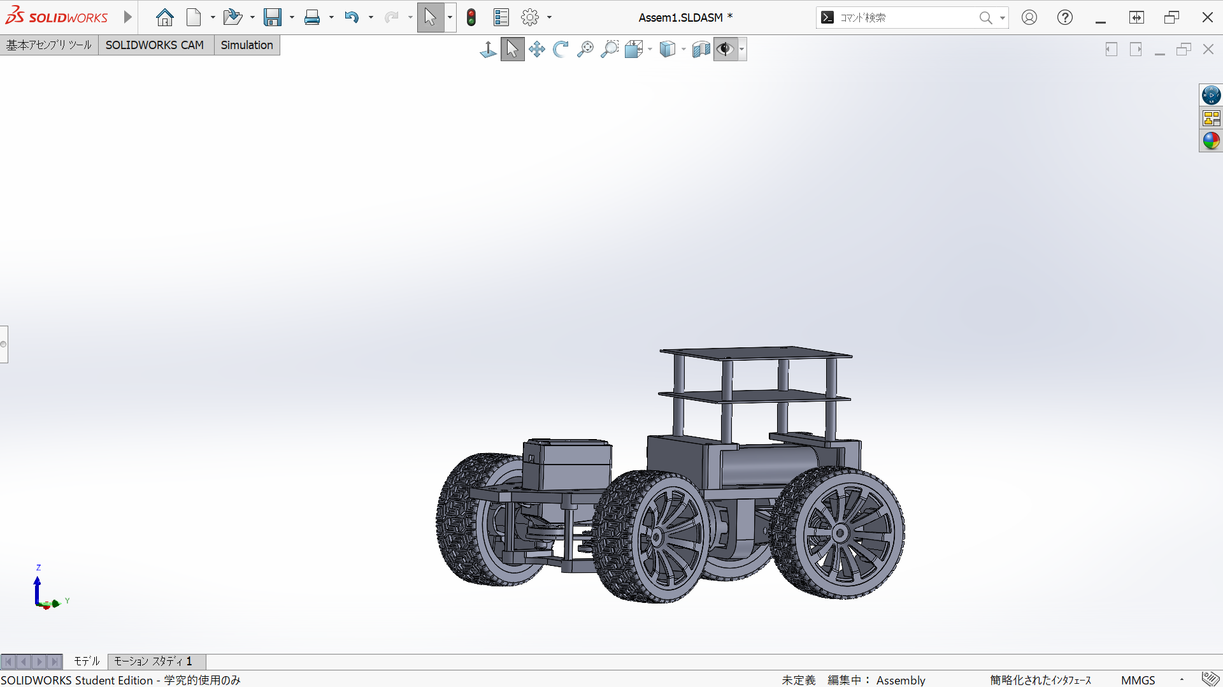
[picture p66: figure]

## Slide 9

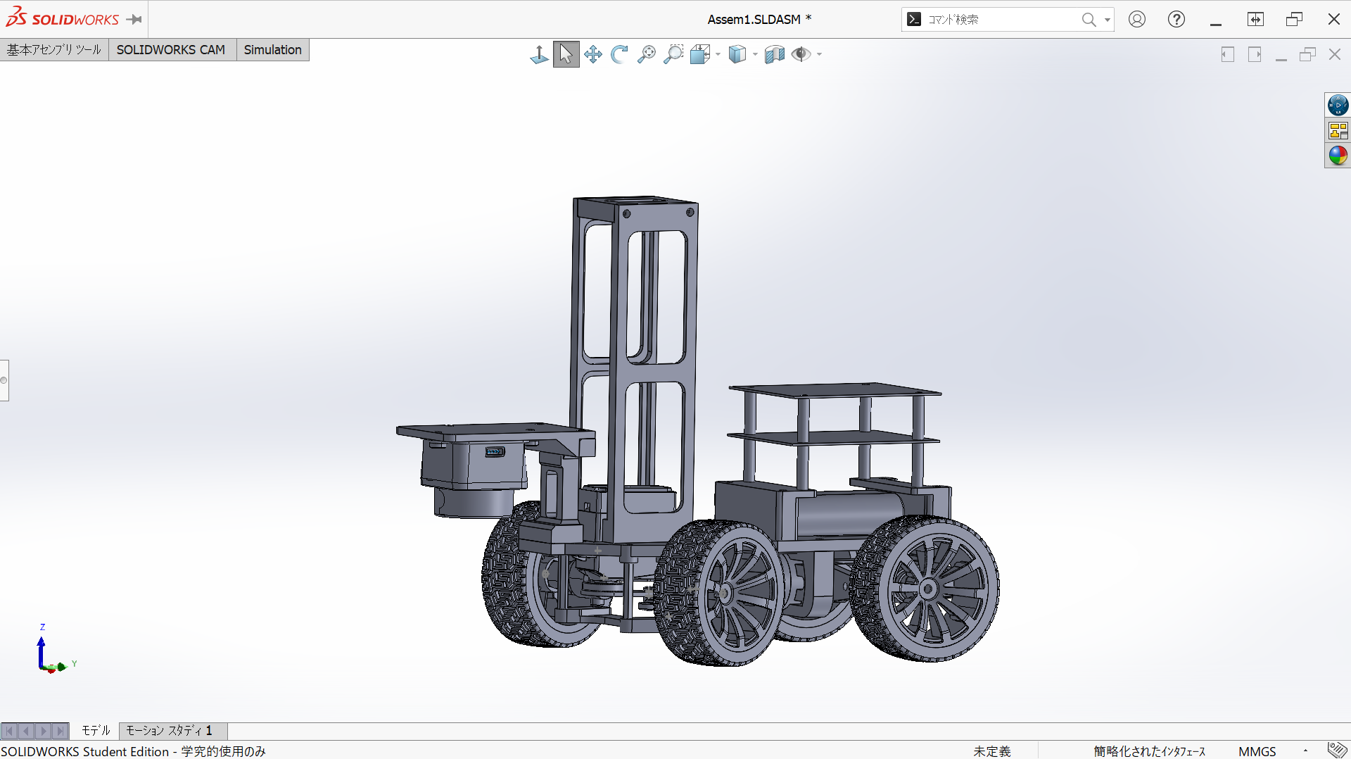
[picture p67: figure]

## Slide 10

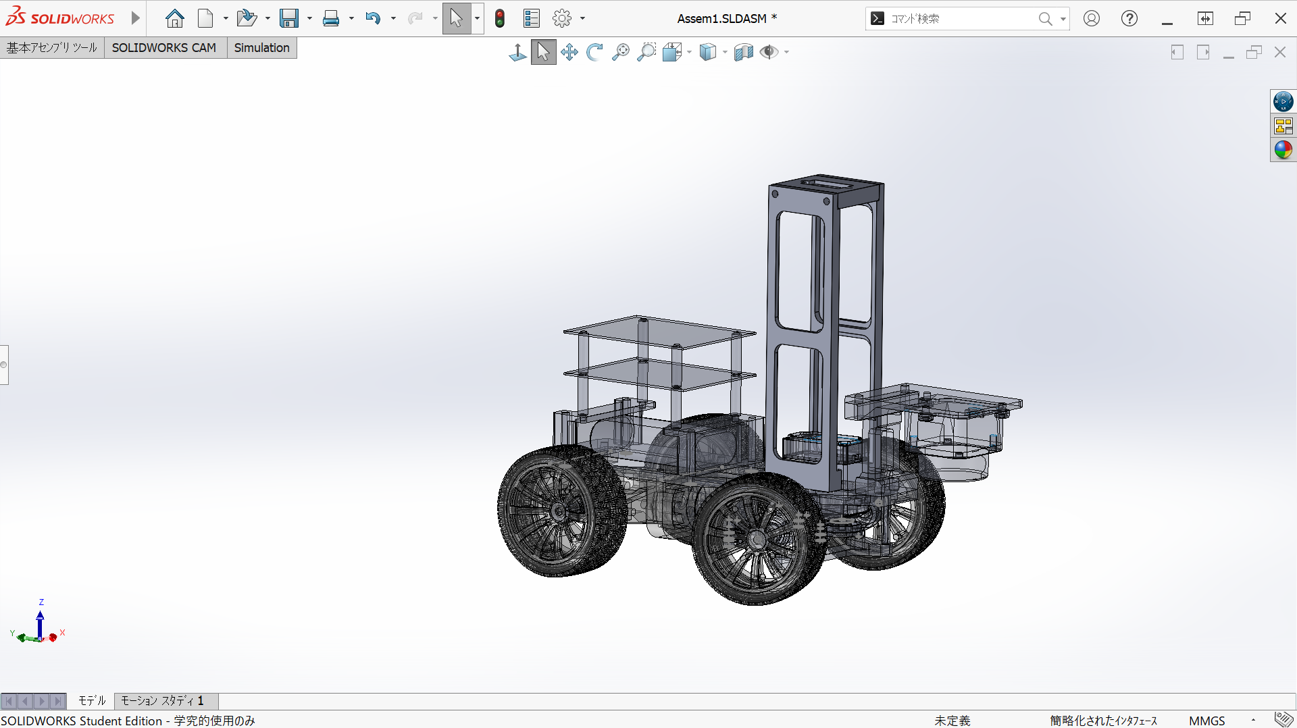
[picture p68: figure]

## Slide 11

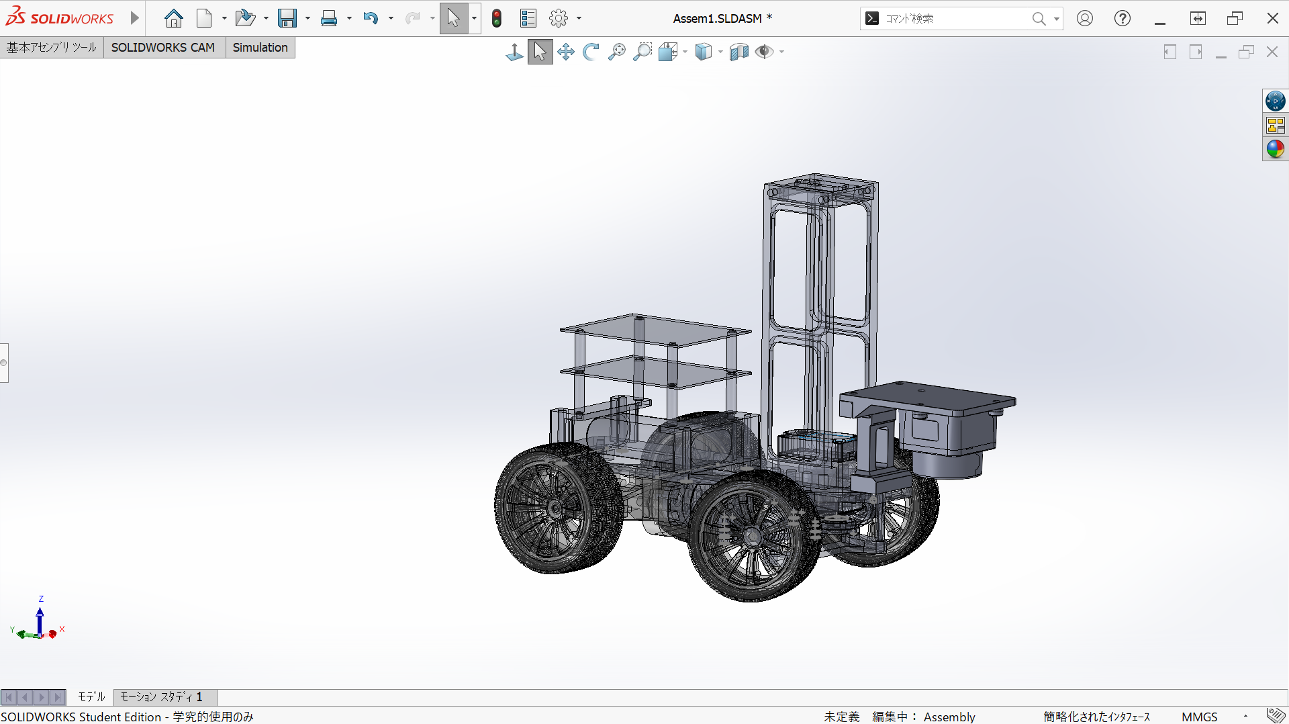
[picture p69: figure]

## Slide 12

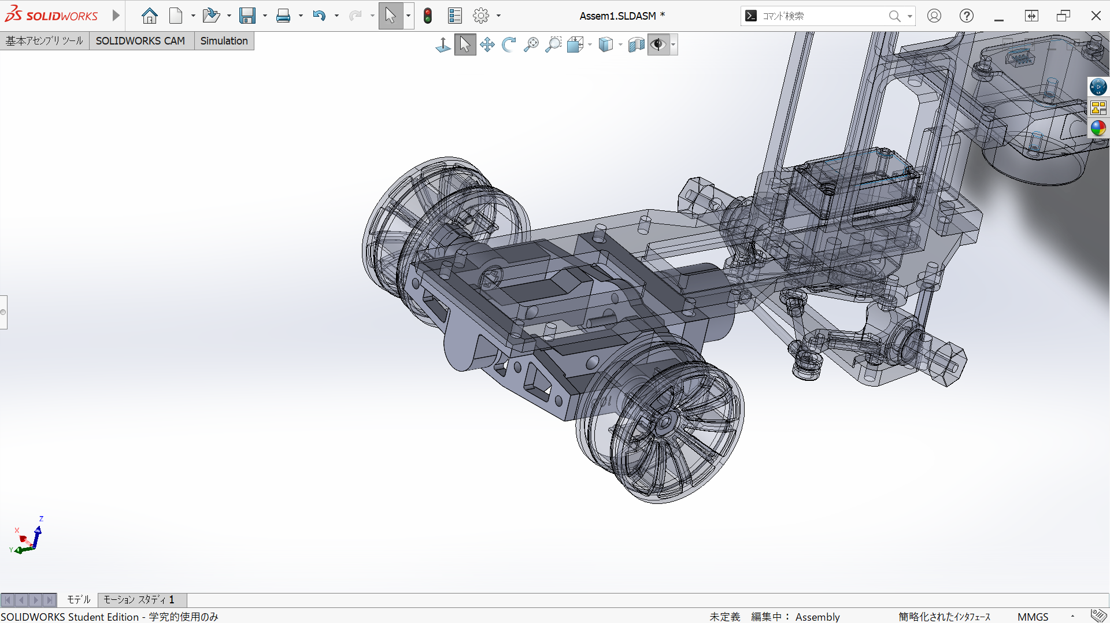
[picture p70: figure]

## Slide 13

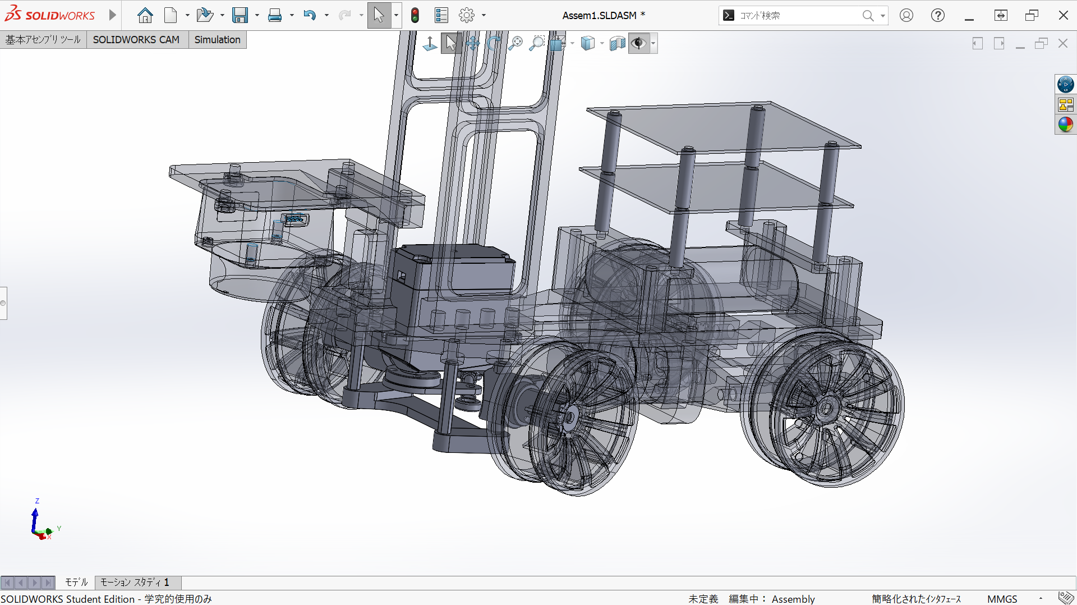
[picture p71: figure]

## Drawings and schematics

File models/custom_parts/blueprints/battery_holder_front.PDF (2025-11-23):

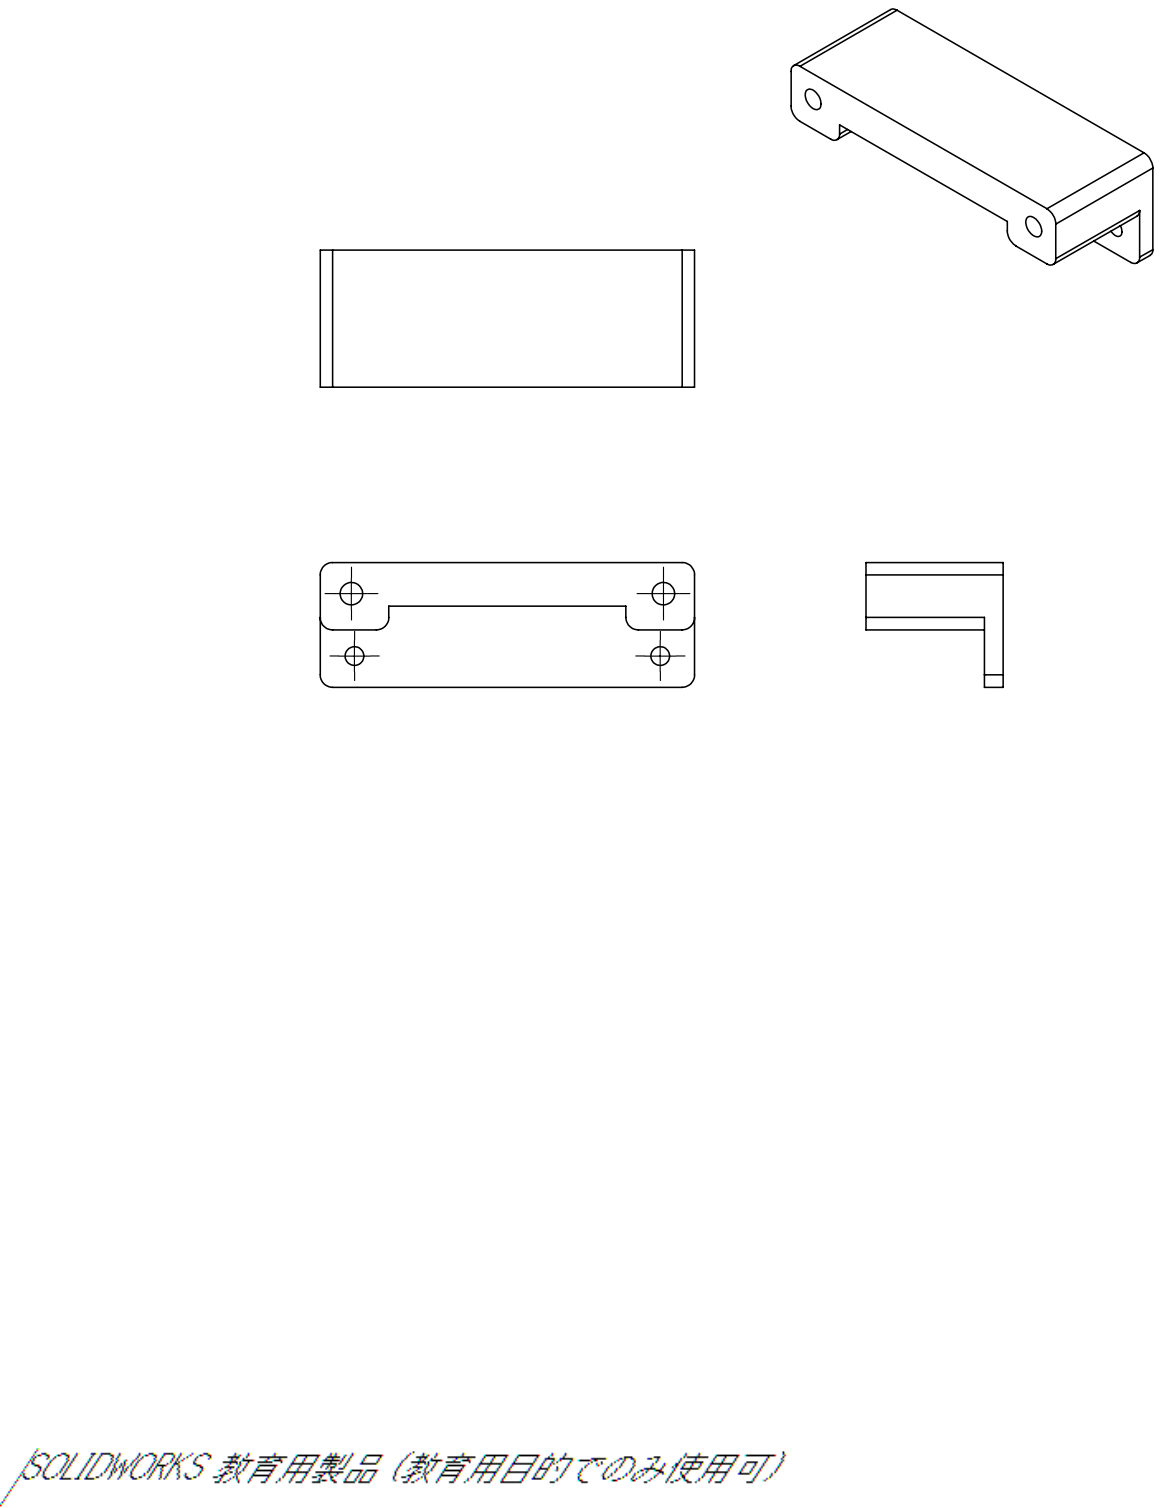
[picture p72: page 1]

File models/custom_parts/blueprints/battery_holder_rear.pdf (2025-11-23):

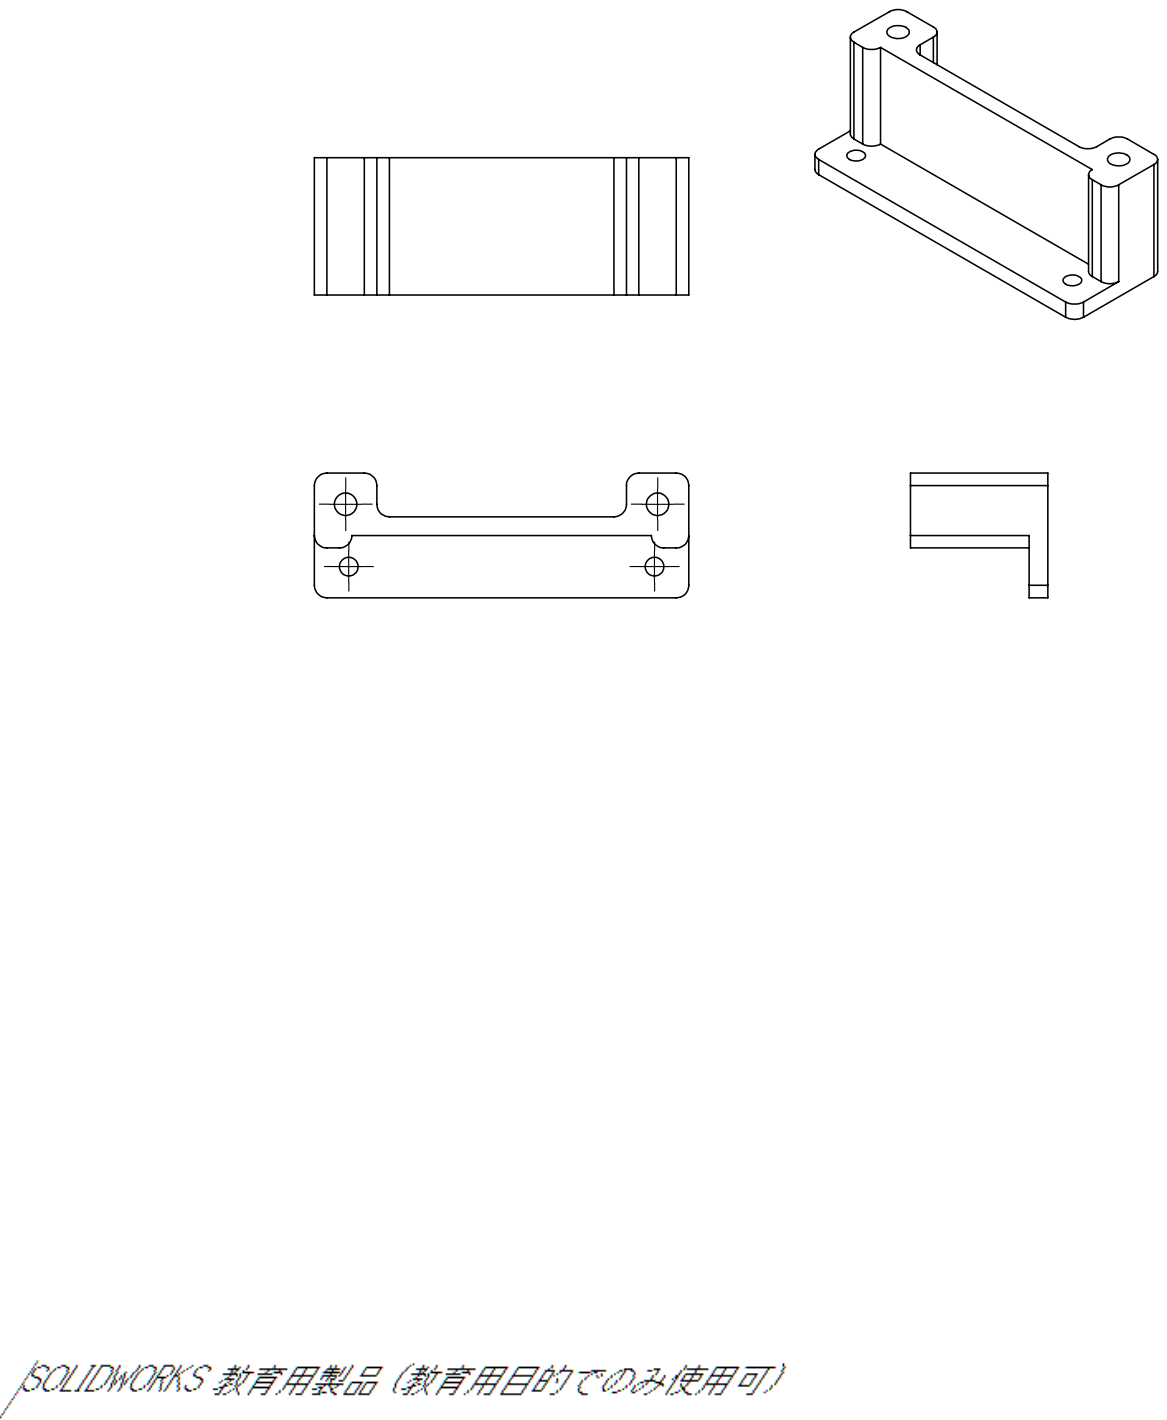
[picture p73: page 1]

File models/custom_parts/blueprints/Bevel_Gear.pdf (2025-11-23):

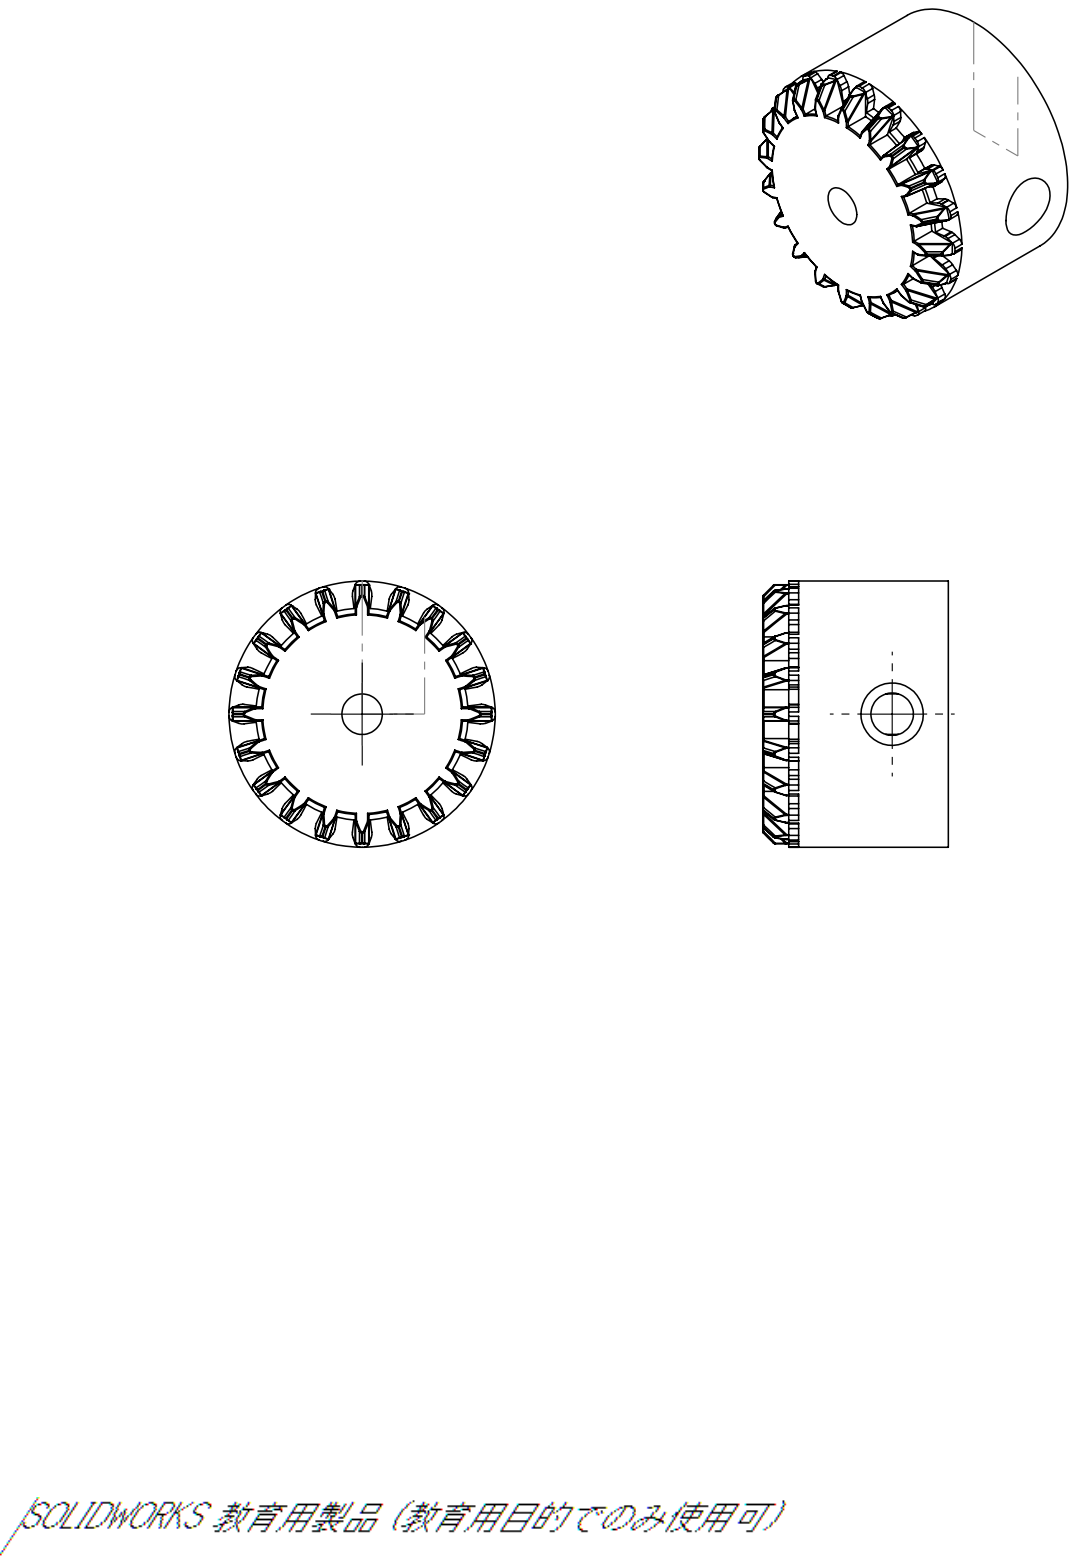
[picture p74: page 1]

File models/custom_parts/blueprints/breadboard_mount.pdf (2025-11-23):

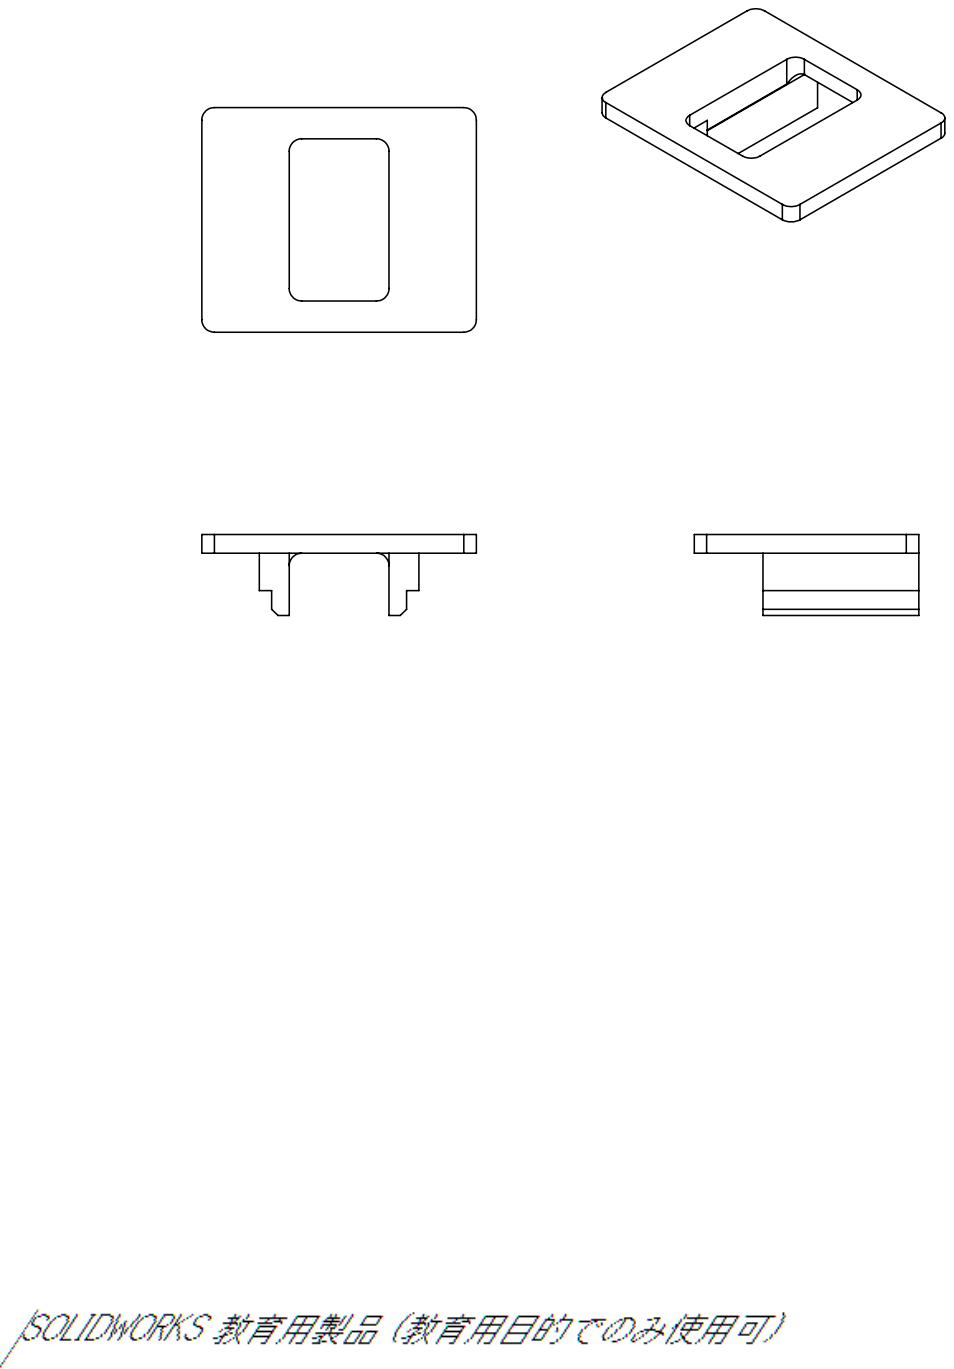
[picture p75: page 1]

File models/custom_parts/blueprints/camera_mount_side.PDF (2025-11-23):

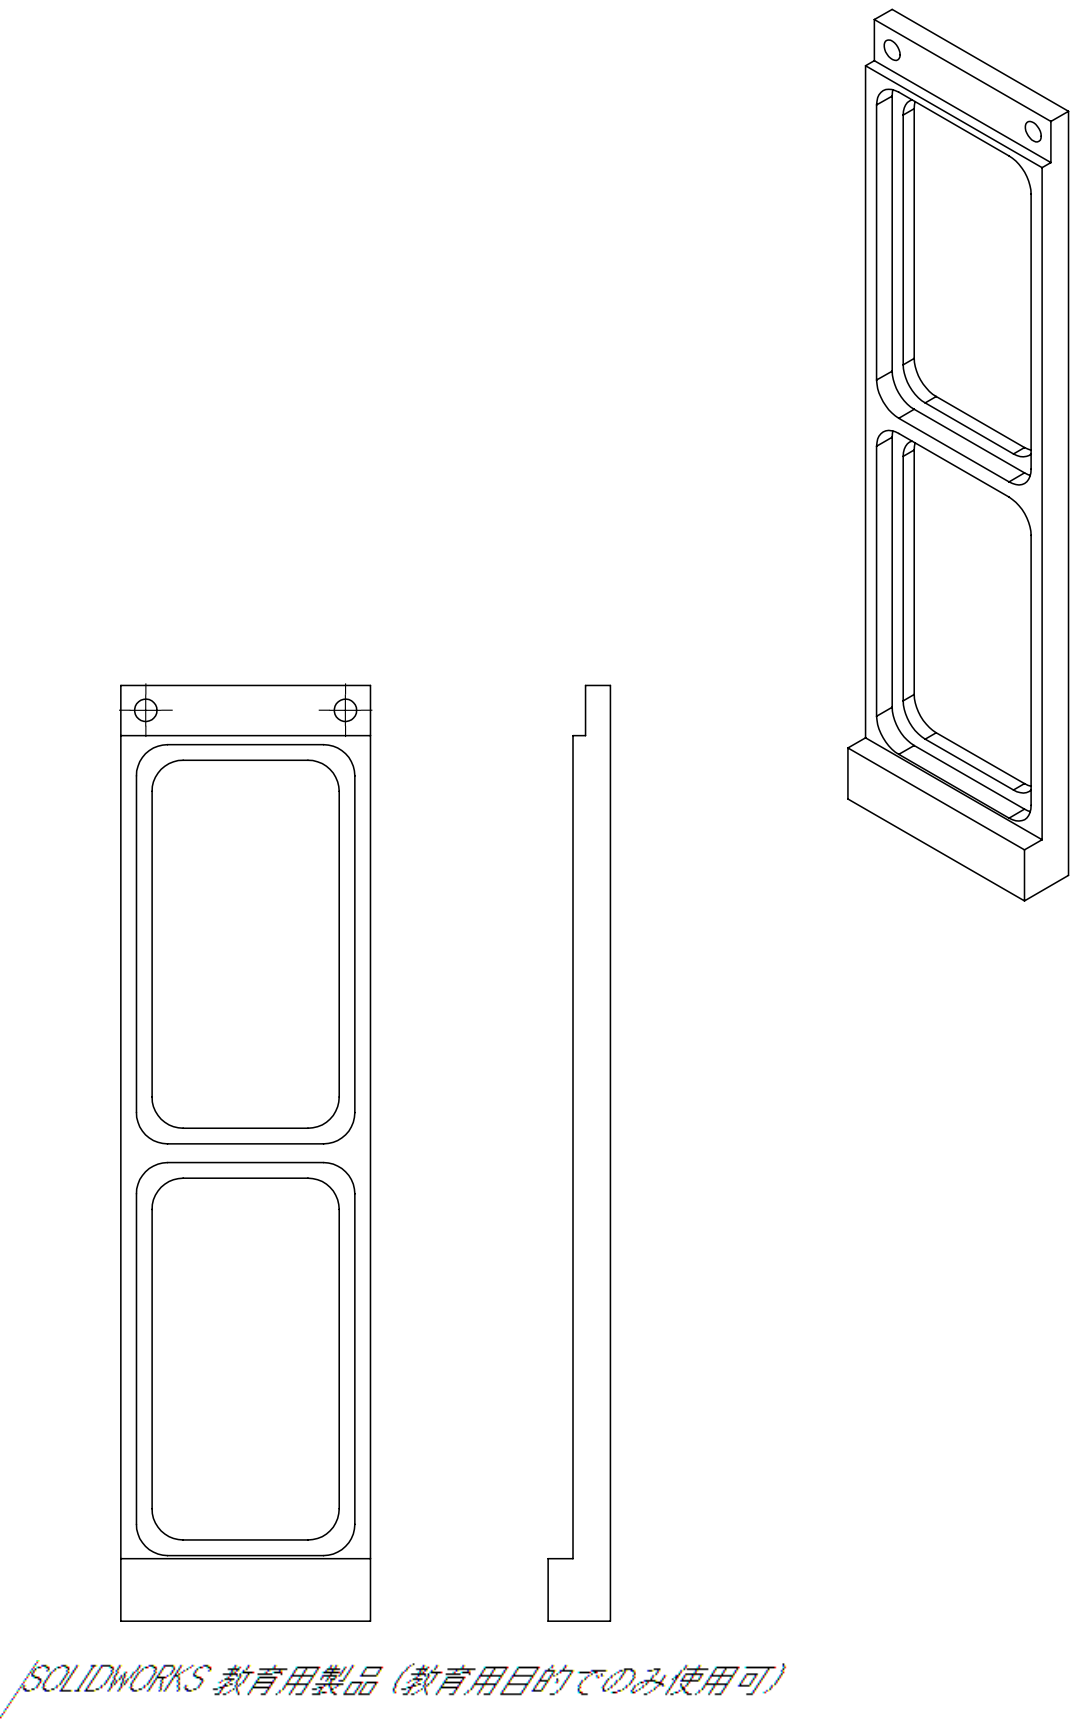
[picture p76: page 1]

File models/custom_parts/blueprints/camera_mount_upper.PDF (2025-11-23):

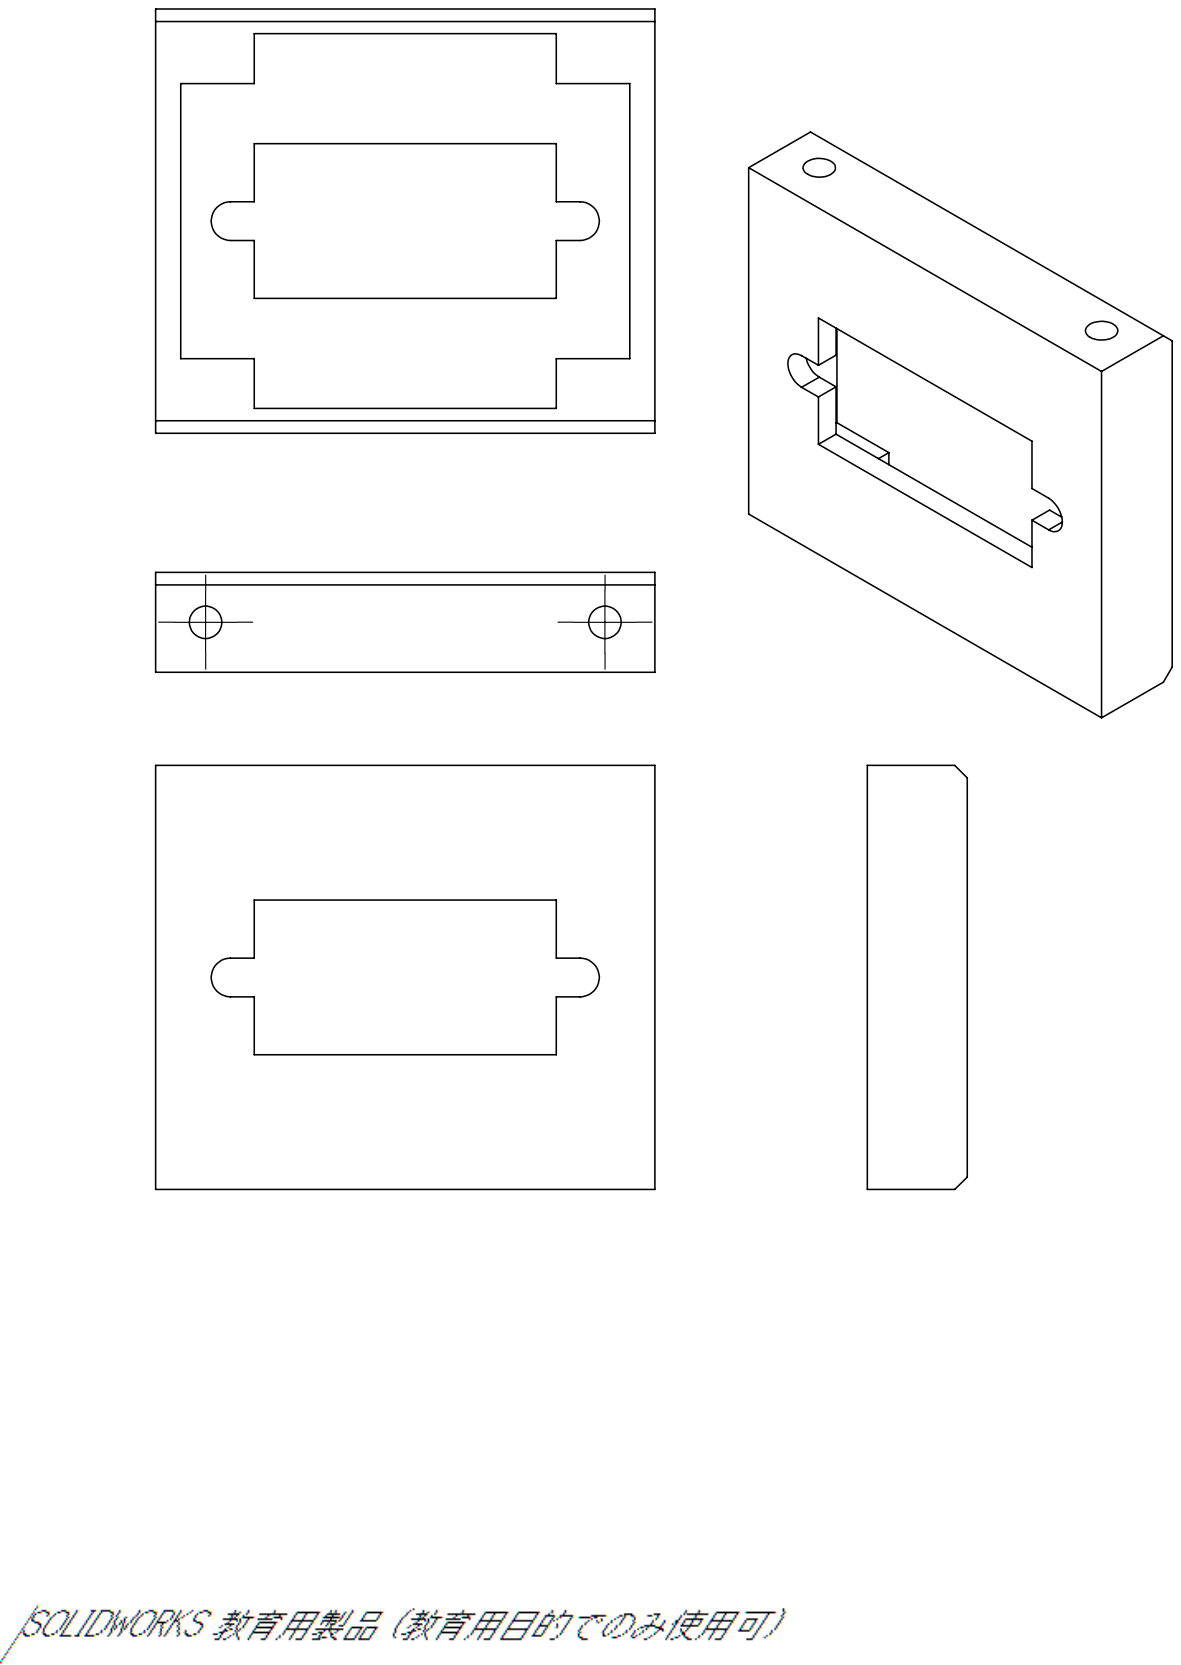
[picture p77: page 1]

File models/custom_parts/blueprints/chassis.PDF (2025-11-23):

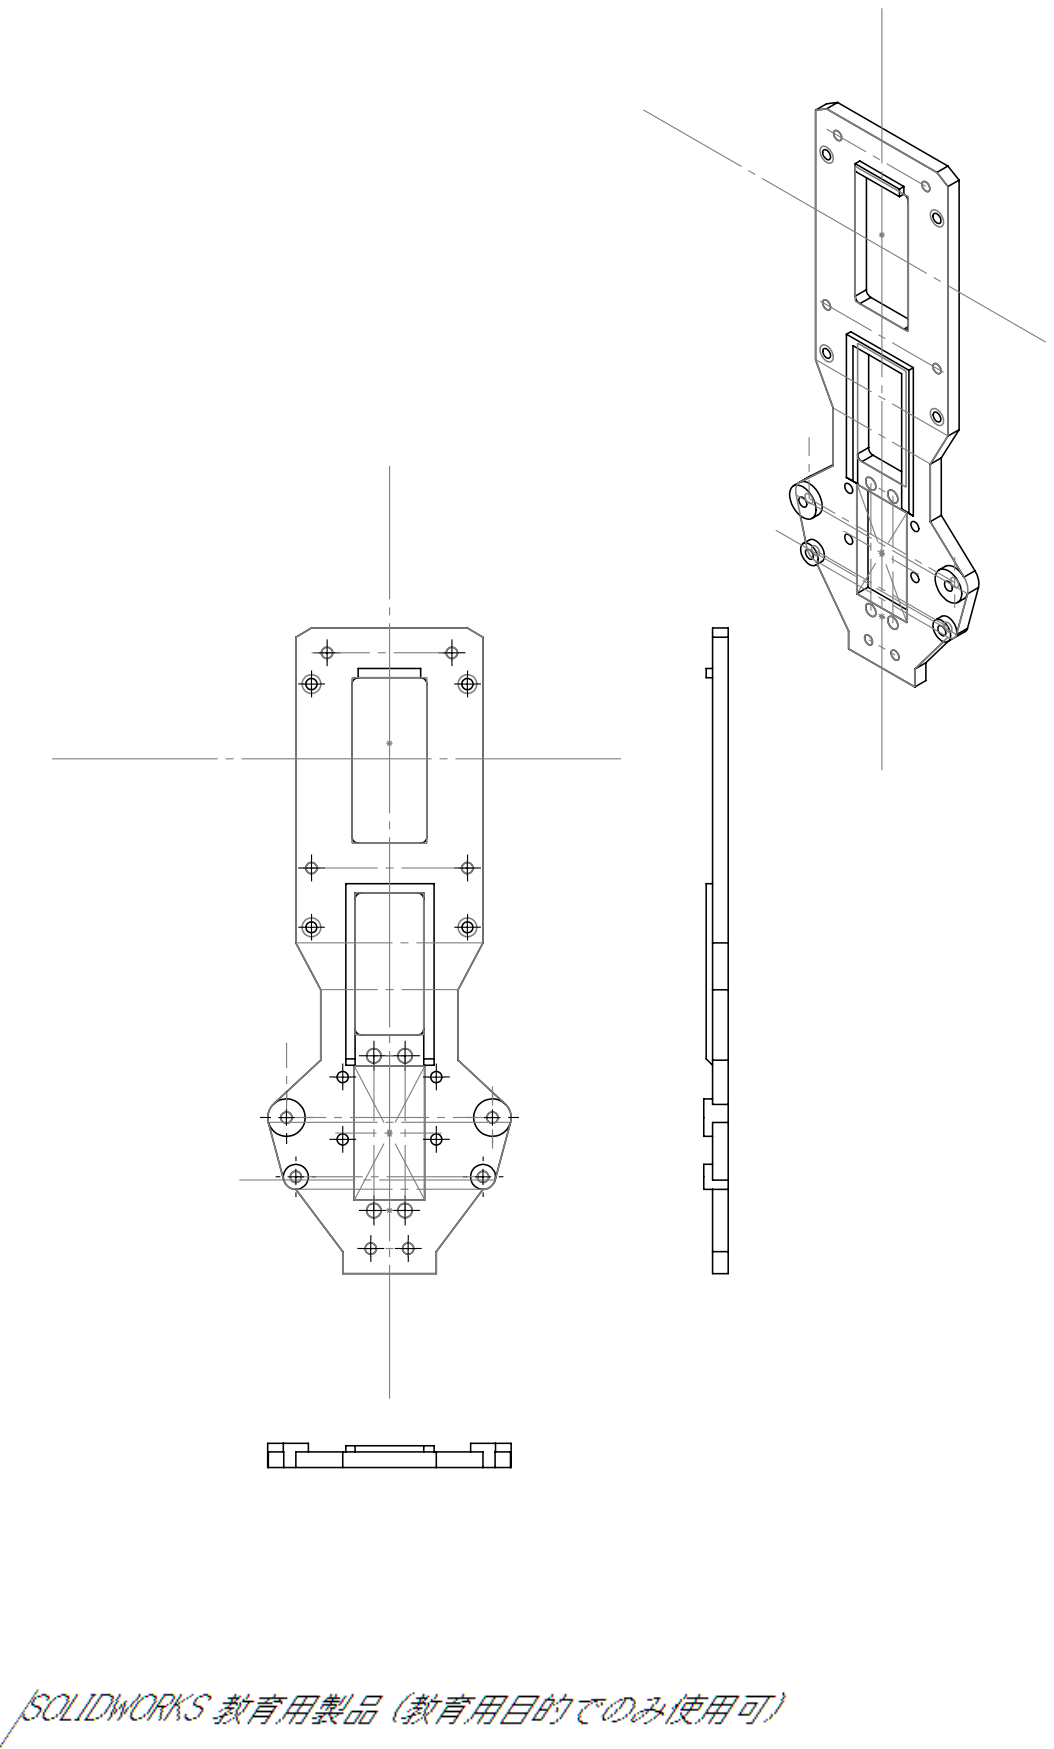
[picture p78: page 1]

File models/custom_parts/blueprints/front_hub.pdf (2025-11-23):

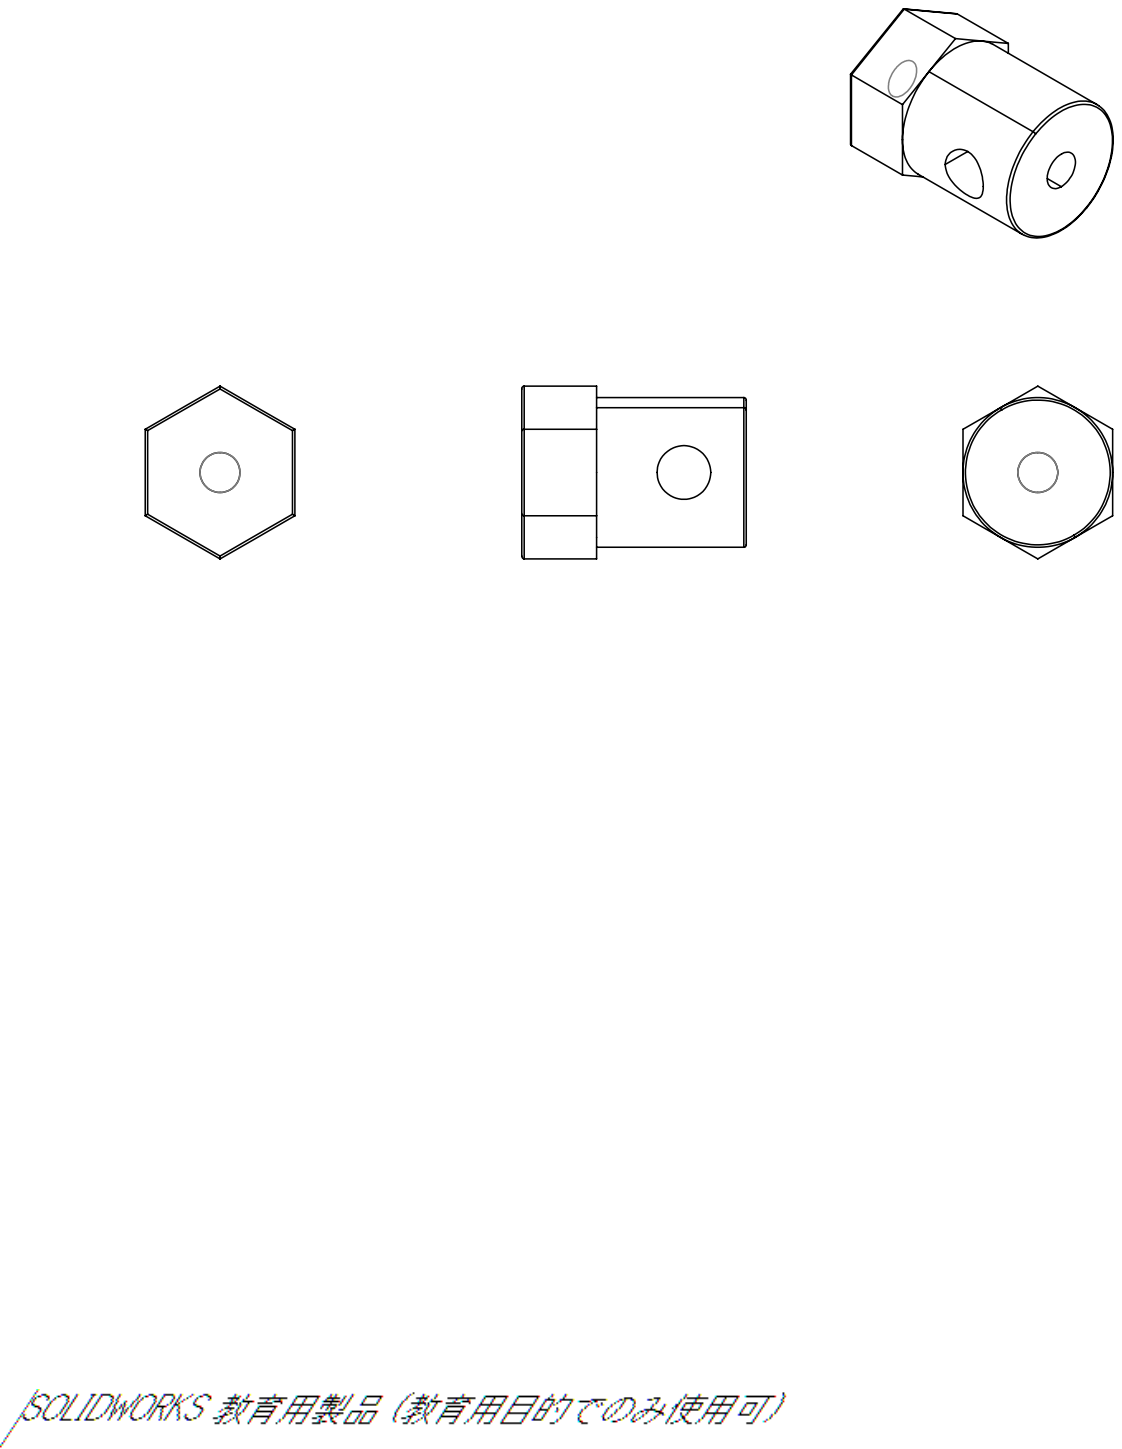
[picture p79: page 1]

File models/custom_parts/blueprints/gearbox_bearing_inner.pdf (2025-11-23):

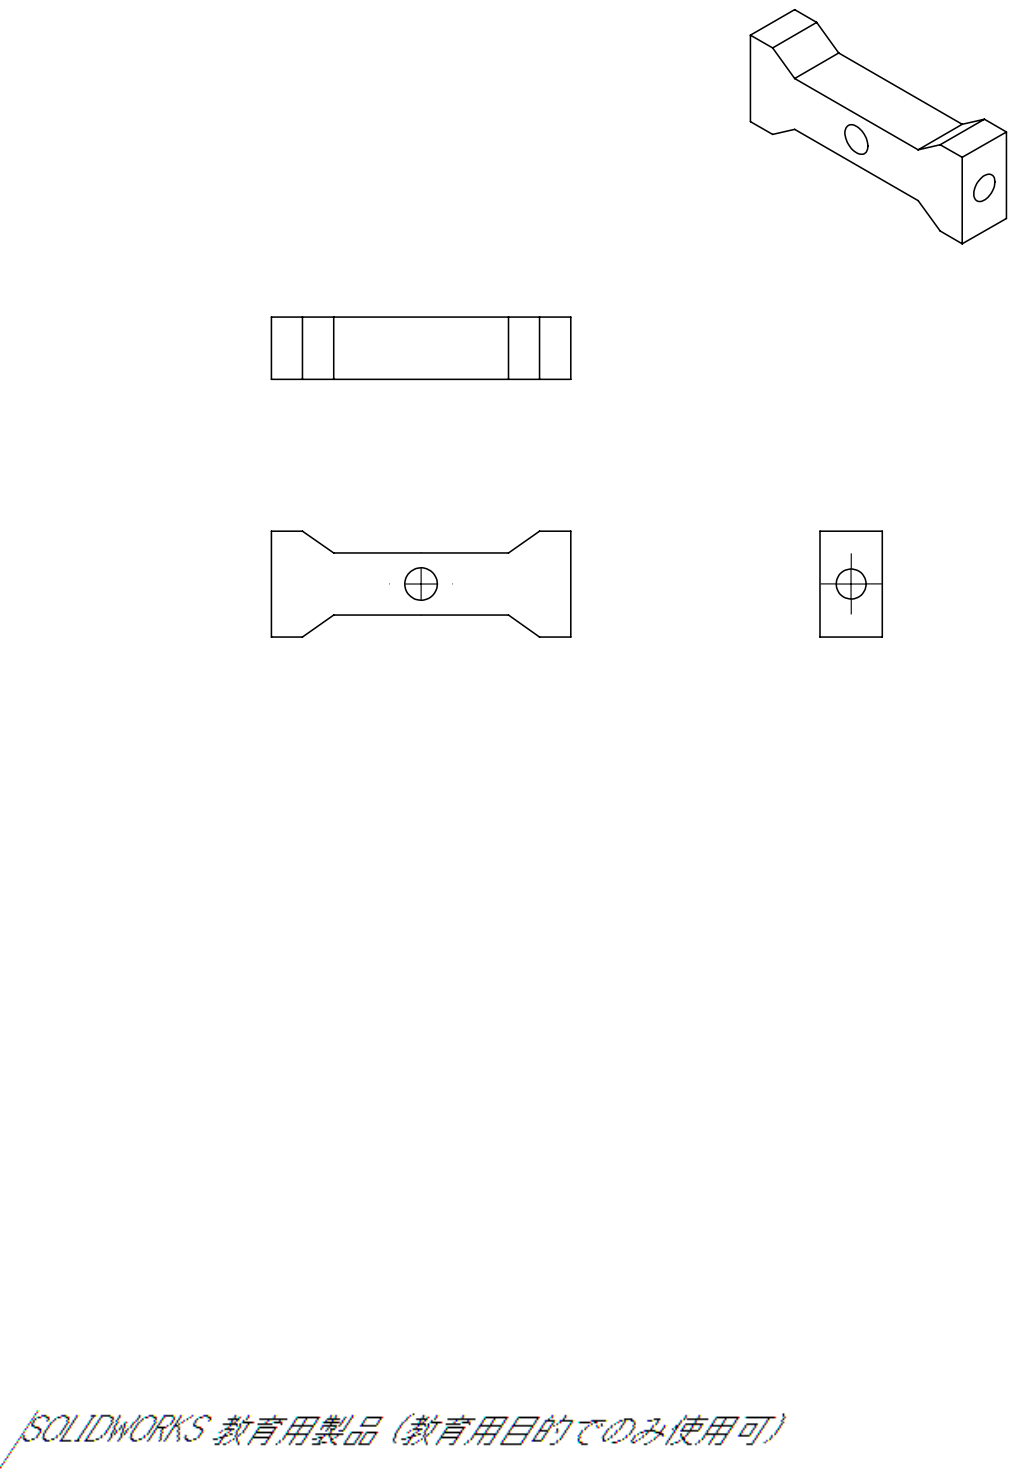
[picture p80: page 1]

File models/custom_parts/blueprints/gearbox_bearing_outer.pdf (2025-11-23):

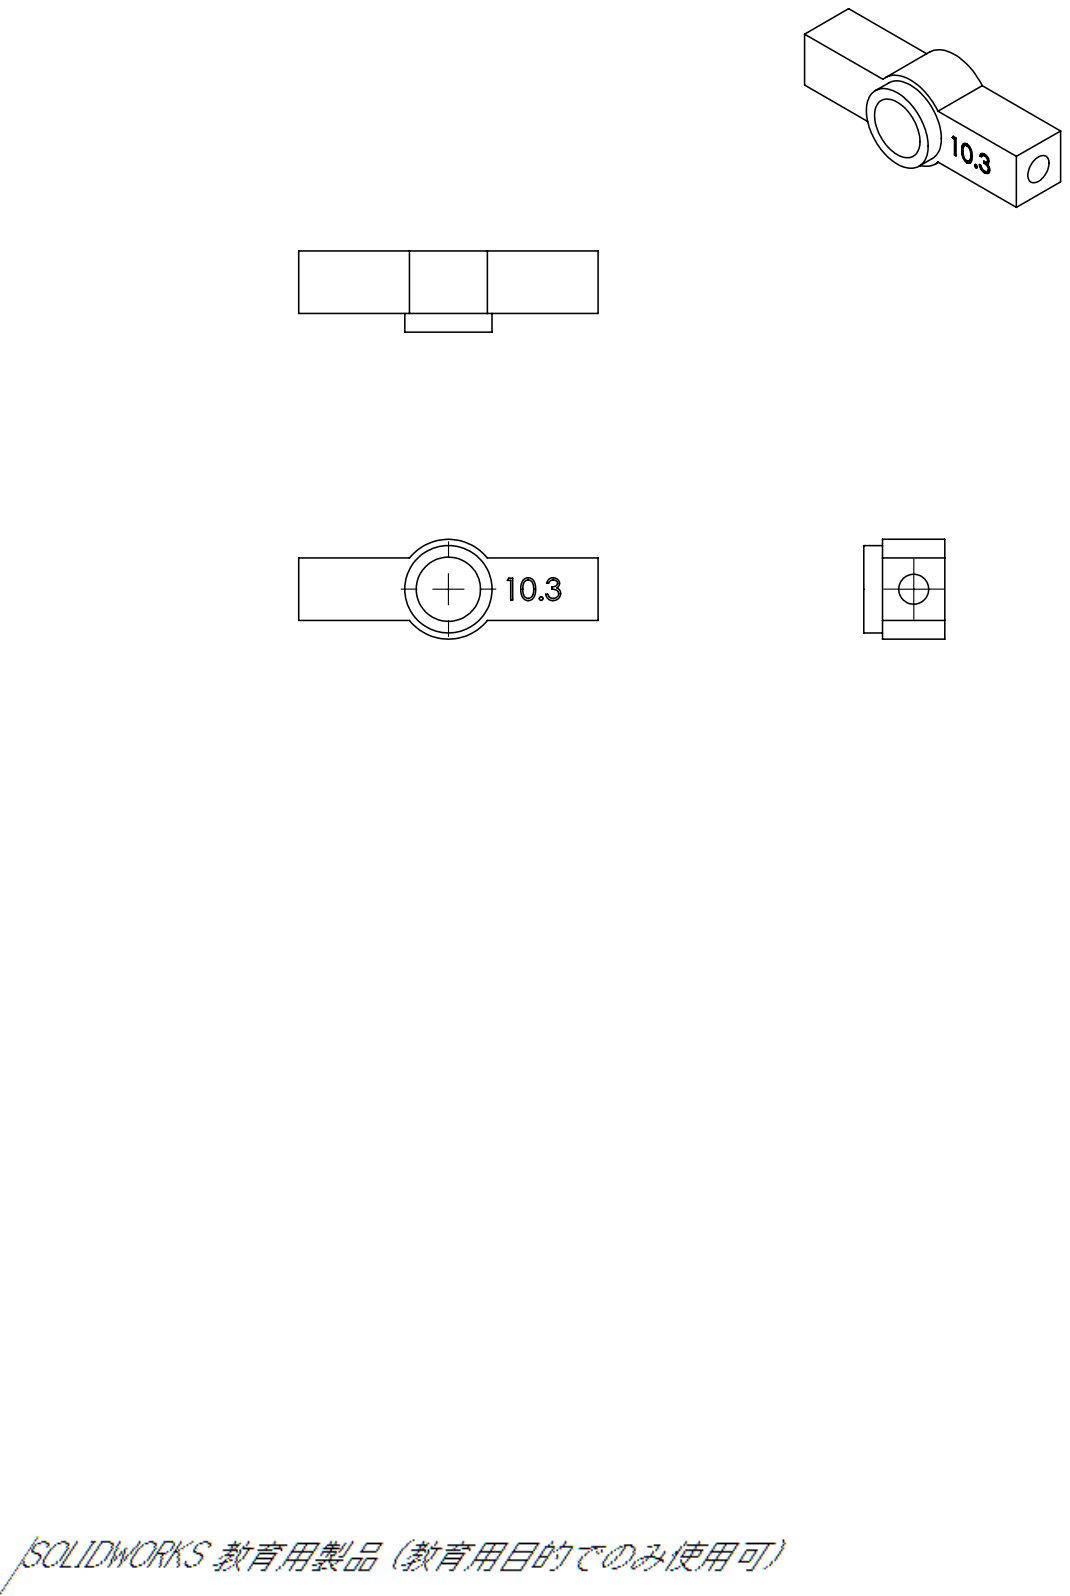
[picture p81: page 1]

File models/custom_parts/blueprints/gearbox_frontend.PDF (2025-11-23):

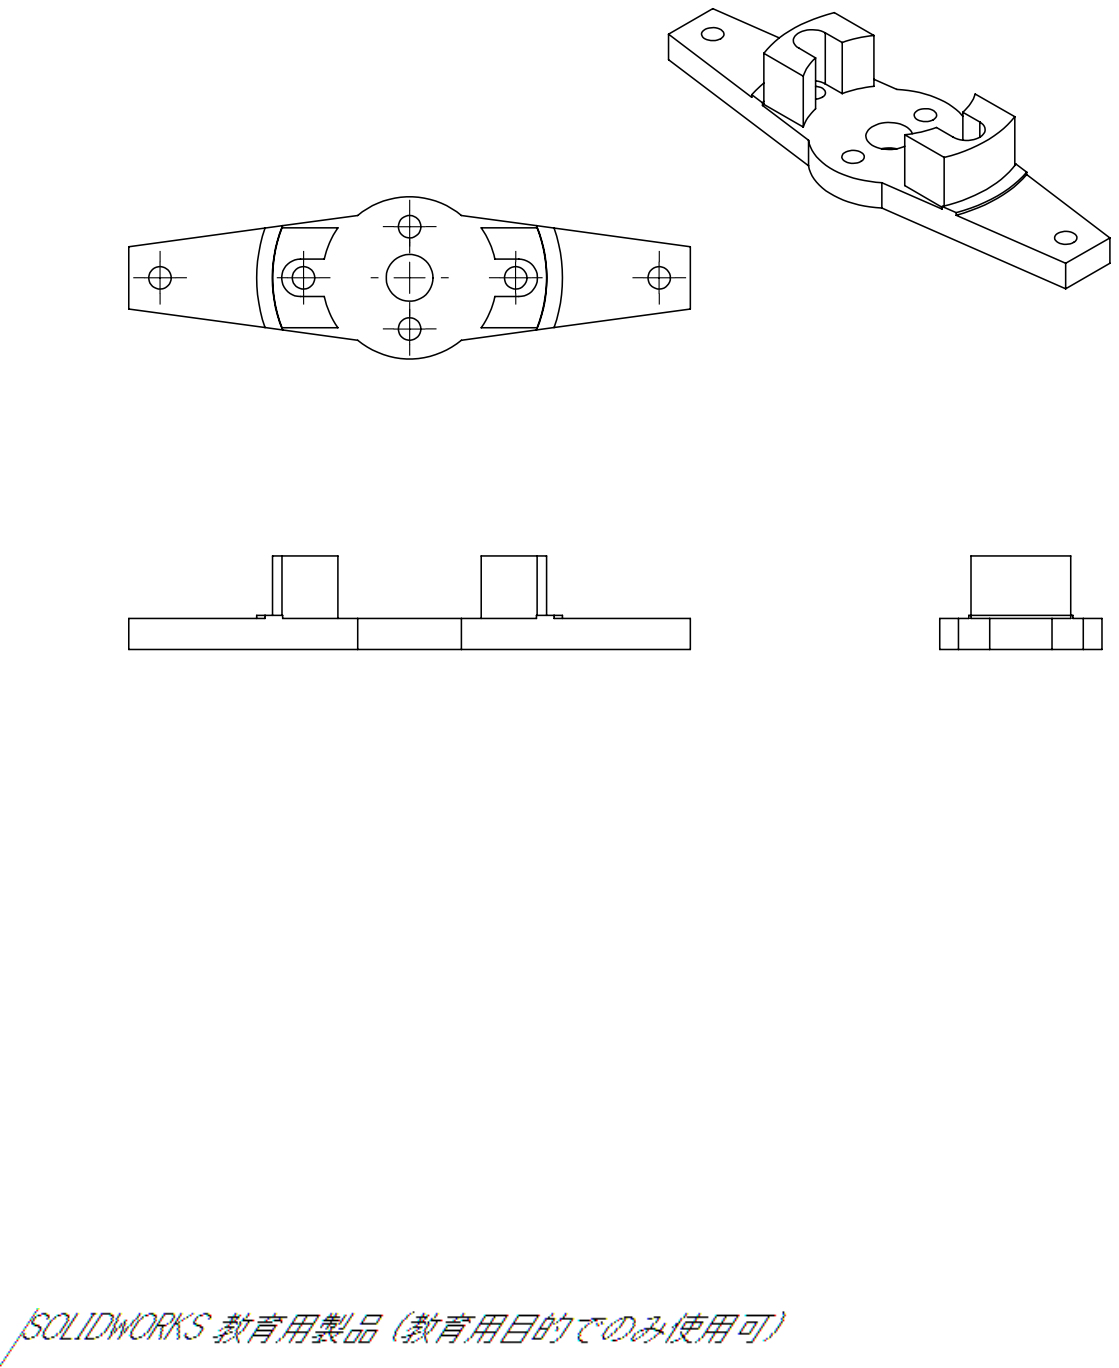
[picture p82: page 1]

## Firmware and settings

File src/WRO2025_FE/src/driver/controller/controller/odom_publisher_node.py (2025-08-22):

#!/usr/bin/env python3
# -*- coding: utf-8 -*-
import os
import math
import time
import rclpy
import signal
import threading
from rclpy.node import Node
from std_srvs.srv import Trigger
from nav_msgs.msg import Odometry
from controller import ackermann, mecanum
from controller import ackermann_original
from ros_robot_controller_msgs.msg import MotorsState, SetPWMServoState, PWMServoState
from geometry_msgs.msg import Pose2D, Pose, Twist, PoseWithCovarianceStamped, TransformStamped
from rclpy.qos import QoSProfile, ReliabilityPolicy, HistoryPolicy

ODOM_POSE_COVARIANCE = list(map(float, 
                        [1e-3, 0, 0, 0, 0, 0, 
                        0, 1e-3, 0, 0, 0, 0,
                        0, 0, 1e6, 0, 0, 0,
                        0, 0, 0, 1e6, 0, 0,
                        0, 0, 0, 0, 1e6, 0,
                        0, 0, 0, 0, 0, 1e3]))

ODOM_POSE_COVARIANCE_STOP = list(map(float, 
                            [1e-9, 0, 0, 0, 0, 0, 
                             0, 1e-3, 1e-9, 0, 0, 0,
                             0, 0, 1e6, 0, 0, 0,
                             0, 0, 0, 1e6, 0, 0,
                             0, 0, 0, 0, 1e6, 0,
                             0, 0, 0, 0, 0, 1e-9]))

ODOM_TWIST_COVARIANCE = list(map(float, 
                        [1e-3, 0, 0, 0, 0, 0, 
                         0, 1e-3, 0, 0, 0, 0,
                         0, 0, 1e6, 0, 0, 0,
                         0, 0, 0, 1e6, 0, 0,
                         0, 0, 0, 0, 1e6, 0,
                         0, 0, 0, 0, 0, 1e3]))

ODOM_TWIST_COVARIANCE_STOP = list(map(float, 
                            [1e-9, 0, 0, 0, 0, 0, 
                              0, 1e-3, 1e-9, 0, 0, 0,
                              0, 0, 1e6, 0, 0, 0,
                              0, 0, 0, 1e6, 0, 0,
                              0, 0, 0, 0, 1e6, 0,
                              0, 0, 0, 0, 0, 1e-9]))

def rpy2qua(roll, pitch, yaw):
    cy = math.cos(yaw*0.5)
    sy = math.sin(yaw*0.5)
    cp = math.cos(pitch*0.5)
    sp = math.sin(pitch*0.5)
    cr = math.cos(roll * 0.5)
    sr = math.sin(roll * 0.5)
    
    q = Pose()
    q.orientation.w = cy * cp * cr + sy * sp * sr
    q.orientation.x = cy * cp * sr - sy * sp * cr
    q.orientation.y = sy * cp * sr + cy * sp * cr
    q.orientation.z = sy * cp * cr - cy * sp * sr
    return q.orientation

def qua2rpy(x, y, z, w):
    roll = math.atan2(2 * (w * x + y * z), 1 - 2 * (x * x + y * y))
    pitch = math.asin(2 * (w * y - x * z))
    yaw = math.atan2(2 * (w * z + x * y), 1 - 2 * (z * z + y * y))

    return roll, pitch, yaw

class Controller(Node):
    
    def __init__(self, name):
        # rclpy.init()
        super().__init__(name)

        self.lock = threading.Lock()

        self.x = 0.0
        self.y = 0.0
        self.linear_x = 0.0
        self.linear_y = 0.0
        self.angular_z = 0.0
        self.pose_yaw = 0
        self.last_time = None
        self.current_time = None
        signal.signal(signal.SIGINT, self.shutdown)

        self.ackermann = ackermann.AckermannChassis(wheelbase=0.145, track_width=0.133, wheel_diameter=0.067)
        self.mecanum = mecanum.MecanumChassis(wheelbase=0.1368, track_width=0.1446, wheel_diameter=0.065)

        # Initialize the new model for the modified robot.
        # Ensure 'drive_motor_id' matches your hardware. Using 4 as a placeholder.
        self.ackermann_original = ackermann_original.RearDriveAckermannChassis(
            wheelbase=0.145, 
            wheel_diameter=0.067, 
            drive_motor_id=4
        )

        # Declare parameters
        self.declare_parameter('pub_odom_topic', True)
        self.declare_parameter('base_frame_id', 'base_footprint')
        self.declare_parameter('odom_frame_id', 'odom')
        self.declare_parameter('linear_correction_factor', 1.00)
        self.declare_parameter('linear_correction_factor_tank', 0.52)
        self.declare_parameter('angular_correction_factor', 1.00)
        self.declare_parameter('machine_type', os.environ['MACHINE_TYPE'])
        
        self.pub_odom_topic = self.get_parameter('pub_odom_topic').value
        self.base_frame_id = self.get_parameter('base_frame_id').value
        self.odom_frame_id = self.get_parameter('odom_frame_id').value
        
        #self.machine_type = os.environ.get('MACHINE_TYPE', 'MentorPi_Mecanum')
        self.machine_type = self.get_parameter('machine_type').value
        if self.machine_type == 'JetRover_Tank':
            self.linear_factor = self.get_parameter('linear_correction_factor_tank').value
        else:
            self.linear_factor = self.get_parameter('linear_correction_factor').value
        self.angular_factor = self.get_parameter('angular_correction_factor').value

        self.clock = self.get_clock() 
        if self.pub_odom_topic:
            # self.odom_broadcaster = tf2_ros.TransformBroadcaster(self)            # self.odom_trans = TransformStamped()
            # self.odom_trans.header.frame_id = self.odom_frame_id
            # self.odom_trans.child_frame_id = self.base_frame_id
            
            self.odom = Odometry()
            self.odom.header.frame_id = self.odom_frame_id
            self.odom.child_frame_id = self.base_frame_id
            
            self.odom.pose.covariance = ODOM_POSE_COVARIANCE
            self.odom.twist.covariance = ODOM_TWIST_COVARIANCE
            
            self.odom_pub = self.create_publisher(Odometry, 'odom_raw', 1)
            # Replace threading.Thread with this create_timer call
            odom_timer_period = 0.02 # 50Hz, same as time.sleep(0.02)
            self.odom_timer = self.create_timer(odom_timer_period, self.cal_odom_fun)

        self.get_logger().info('\033[1;32m%f %f\033[0m' % (self.linear_factor, self.angular_factor))
        self.motor_pub = self.create_publisher(MotorsState, 'ros_robot_controller/set_motor', 1)
        self.servo_state_pub = self.create_publisher(SetPWMServoState, 'ros_robot_controller/pwm_servo/set_state', 10)
        self.pose_pub = self.create_publisher(PoseWithCovarianceStamped, 'set_pose', 1)
        self.create_subscription(Pose2D, 'set_odom', self.set_odom, 1)
        # self.create_subscription(Twist, 'controller/cmd_vel', self.cmd_vel_callback, 1)
        qos_profile_cmd_vel = QoSProfile(
            reliability=ReliabilityPolicy.RELIABLE,
            history=HistoryPolicy.KEEP_LAST,
            depth=1
        )
        # Add the qos_profile argument to the subscription
        self.create_subscription(
            Twist, 
            'controller/cmd_vel', 
            self.cmd_vel_callback, 
            qos_profile=qos_profile_cmd_vel
        )
        #self.create_subscription(Twist, '/app/cmd_vel', self.acker_cmd_vel_callback, 1)
        self.create_subscription(Twist, 'cmd_vel', self.app_cmd_vel_callback, 1)
        self.create_service(Trigger, 'controller/load_calibrate_param', self.load_calibrate_param)
        self.create_service(Trigger, '~/init_finish', self.get_node_state)
        
        self.get_logger().info('\033[1;32m%s\033[0m' % 'start')

    def get_node_state(self, request, response):
        response.success = True
        return response

    def shutdown(self, signum, frame):
        self.get_logger().info('\033[1;32m%s\033[0m' % 'shutdown')
        rclpy.shutdown()

    def load_calibrate_param(self, request, response):
        if self.machine_type == 'JetRover_Tank':
            self.linear_factor = self.get_parameter('~linear_correction_factor_tank').value or 0.52
        else:
            self.linear_factor = self.get_parameter('~linear_correction_factor').value or 1.00
        self.angular_factor = self.get_parameter('~angular_correction_factor').value or 1.00
        self.get_logger().info('\033[1;32m%s\033[0m' % 'load_calibrate_param')

        response.success = True
        return response

    def set_odom(self, msg):
        self.odom = Odometry()
        self.odom.header.frame_id = self.odom_frame_id
        self.odom.child_frame_id = self.base_frame_id
        
        self.odom.pose.covariance = ODOM_POSE_COVARIANCE
        self.odom.twist.covariance = ODOM_TWIST_COVARIANCE
        self.odom.pose.pose.position.x = msg.x
        self.odom.pose.pose.position.y = msg.y
        self.pose_yaw = msg.theta
        self.odom.pose.pose.orientation = rpy2qua(0, 0, self.pose_yaw)
        
        self.linear_x = 0
        self.linear_y = 0
        self.angular_z = 0
        
        pose = PoseWithCovarianceStamped()
        pose.header.frame_id = self.odom_frame_id
        pose.header.stamp = self.clock().now().to_msg()
        pose.pose.pose = self.odom.pose.pose
        pose.pose.covariance = ODOM_POSE_COVARIANCE
        self.pose_pub.publish(pose)

    def app_cmd_vel_callback(self, msg):
        if msg.linear.x > 0.2:
            msg.linear.x = 0.2
        if msg.linear.x < -0.2:
            msg.linear.x = -0.2
        if msg.linear.y > 0.2:
            msg.linear.y = 0.2
        if msg.linear.y < -0.2:
            msg.linear.y = -0.2
        if msg.angular.z > 0.5:
            msg.angular.z = 0.5
        if msg.angular.z < -0.5:
            msg.angular.z = -0.5
        self.cmd_vel_callback(msg)
    # def cmd_vel_callback(self, msg):
    #     if self.machine_type == 'MentorPi_Mecanum':
    #         self.linear_x = msg.linear.x
    #         self.linear_y = msg.linear.y
    #         self.angular_z = msg.angular.z
    #         speeds = self.mecanum.set_velocity(self.linear_x, self.linear_y, self.angular_z)
    #         self.motor_pub.publish(speeds)
    #     elif self.machine_type == 'MentorPi_Acker':
    #         self.linear_x = msg.linear.x
    #         if msg.angular.z != 0:
    #             r = self.linear_x / msg.angular.z
    #             self.angular_z = msg.angular.z
    #         else:
    #             self.angular_z = 0.0
    #         speeds = self.ackermann.set_velocity(self.linear_x, self.angular_z)
    #         self.motor_pub.publish(speeds[1])
    #         if speeds[0] is not None:
    #             servo_state = PWMServoState()
    #             servo_state.id = [3]
    #             servo_state.position = [int(speeds[0])]
    #             data = SetPWMServoState()
    #             data.state = [servo_state]
    #             data.duration = 0.02
    #             self.servo_state_pub.publish(data)
    def cmd_vel_callback(self, msg):
        # Step 1: Safely update shared variables for the odometry thread.
        with self.lock:
            self.linear_x = msg.linear.x
            self.linear_y = msg.linear.y if self.machine_type == 'MentorPi_Mecanum' else 0.0
            self.angular_z = msg.angular.z

        # Step 2: Calculate and publish motor/servo commands based on machine type.
        # This section uses the fresh 'msg' object for calculations.
        if self.machine_type == 'MentorPi_Mecanum':
            speeds = self.mecanum.set_velocity(msg.linear.x, msg.linear.y, msg.angular.z)
            self.motor_pub.publish(speeds)

        elif self.machine_type == 'MentorPi_Acker':
            # Calculate speeds using the standard Ackermann model
            speeds = self.ackermann.set_velocity(msg.linear.x, msg.angular.z)
            self.motor_pub.publish(speeds[1])
            
            if speeds[0] is not None:
                servo_state = PWMServoState()
                servo_state.id = [3]
                servo_state.position = [int(speeds[0])]
                data = SetPWMServoState()
                data.state = [servo_state]
                data.duration = 0.02
                self.servo_state_pub.publish(data)
        
        elif self.machine_type == 'MentorPi_Acker_Original':
            # Calculate speeds using the specific "Original" Ackermann model
            speeds = self.ackermann_original.set_velocity(msg.linear.x, msg.angular.z)
            self.motor_pub.publish(speeds[1])
            
            if speeds[0] is not None:
                servo_state = PWMServoState()
                servo_state.id = [3] 
                servo_state.position = [int(speeds[0])]
                data = SetPWMServoState()
                data.state = [servo_state]
                data.duration = 0.02
                self.servo_state_pub.publish(data)

    def cal_odom_fun(self):
        # Lock the section where shared variables are read
        with self.lock:
            # Copy shared values to local variables immediately after acquiring the lock
            linear_x = self.linear_x
            linear_y = self.linear_y
            angular_z = self.angular_z

            # Use ROS clock for time calculation, which is safer
            current_time = self.get_clock().now()
            if self.last_time is None:
                self.last_time = current_time
                dt = 0.0
            else:
                dt = (current_time - self.last_time).nanoseconds / 1e9
            
            self.last_time = current_time

            delta_x = linear_x * dt * math.cos(self.pose_yaw)
            delta_y = linear_y * dt * math.sin(self.pose_yaw) # Note: linear_y is often 0 for Ackermann
            delta_yaw = angular_z * dt

            self.x += delta_x
            self.y += delta_y
            self.pose_yaw += delta_yaw

            self.odom.header.stamp = current_time.to_msg()
            self.odom.pose.pose.position.x = self.linear_factor * self.x
            self.odom.pose.pose.position.y = self.linear_factor * self.y
            self.odom.pose.pose.orientation = rpy2qua(0.0, 0.0, self.pose_yaw)
            
            # Use the local variables for twist
            self.odom.twist.twist.linear.x = linear_x
            self.odom.twist.twist.linear.y = linear_y
            self.odom.twist.twist.angular.z = angular_z

            if linear_x == 0 and linear_y == 0 and angular_z == 0:
                self.odom.pose.covariance = ODOM_POSE_COVARIANCE_STOP
                self.odom.twist.covariance = ODOM_TWIST_COVARIANCE_STOP
            else:
                self.odom.pose.covariance = ODOM_POSE_COVARIANCE
                self.odom.twist.covariance = ODOM_TWIST_COVARIANCE
        
        # Publish outside the lock
        self.odom_pub.publish(self.odom)


def main():
    rclpy.init() # ADD THIS LINE AT THE TOP
    node = Controller('odom_publisher')
    try:
        rclpy.spin(node)
    except KeyboardInterrupt:
        node.get_logger().info('KeyboardInterrupt, shutting down...')
    finally:
        node.destroy_node()
        rclpy.shutdown()

if __name__ == "__main__":
    main()

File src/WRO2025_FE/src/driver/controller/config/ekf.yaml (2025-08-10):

### ekf config file ###
/**:
    ros__parameters:
      use_sim_time: false  
      # The frequency, in Hz, at which the filter will output a position estimate. Note that the filter will not begin
      # computation until it receives at least one message from one of the inputs. It will then run continuously at the
      # frequency specified here, regardless of whether it receives more measurements. Defaults to 30 if unspecified.
      frequency: 20.0

      # The period, in seconds, after which we consider a sensor to have timed out. In this event, we carry out a predict
      # cycle on the EKF without correcting it. This parameter can be thought of as the minimum frequency with which the
      # filter will generate new output. Defaults to 1 / frequency if not specified.
      sensor_timeout: 2.0

      # ekf_localization_node and ukf_localization_node both use a 3D omnidirectional motion model. If this parameter is
      # set to true, no 3D information will be used in your state estimate. Use this if you are operating in a planar
      # environment and want to ignore the effect of small variations in the ground plane that might otherwise be detected
      # by, for example, an IMU. Defaults to false if unspecified.
      two_d_mode: true

      # Use this parameter to provide an offset to the transform generated by ekf_localization_node. This can be used for
      # future dating the transform, which is required for interaction with some other packages. Defaults to 0.0 if
      # unspecified.
      transform_time_offset: 0.0

      # Use this parameter to provide specify how long the tf listener should wait for a transform to become available. 
      # Defaults to 0.0 if unspecified.
      transform_timeout: 0.2

      # If you're having trouble, try setting this to true, and then echo the /diagnostics_agg topic to see if the node is
      # unhappy with any settings or data.
      print_diagnostics: false

      # Debug settings. Not for the faint of heart. Outputs a ludicrous amount of information to the file specified by
      # debug_out_file. I hope you like matrices! Please note that setting this to true will have strongly deleterious
      # effects on the performance of the node. Defaults to false if unspecified.
      debug: false

      # Defaults to "robot_localization_debug.txt" if unspecified. Please specify the full path.
      debug_out_file: /path/to/debug/file.txt

      # Whether we'll allow old measurements to cause a re-publication of the updated state
      permit_corrected_publication: false

      # Whether to publish the acceleration state. Defaults to false if unspecified.
      publish_acceleration: false

      # Whether to broadcast the transformation over the /tf topic. Defaults to true if unspecified.
      publish_tf: true
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

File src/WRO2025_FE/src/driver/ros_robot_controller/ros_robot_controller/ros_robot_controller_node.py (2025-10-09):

#!/usr/bin/env python3
# encoding: utf-8
# @Date: 2023/08/28
# Simplified stm32 ros2 package for WRO2025 project

import rclpy
import threading
import yaml
from rclpy.node import Node
from std_srvs.srv import Trigger
from std_msgs.msg import UInt16, Bool
from ros_robot_controller.ros_robot_controller_sdk import Board, PacketReportKeyEvents
from ros_robot_controller_msgs.srv import GetPWMServoState
from ros_robot_controller_msgs.msg import (
    ButtonState, BuzzerState, MotorsState, LedState,
    SetPWMServoState, PWMServoState
)

class RosRobotController(Node):

    def __init__(self, name):
        super().__init__(name)
        
        self.board = Board(logger=self.get_logger())
        self.board.enable_reception()

        self.declare_parameter('init_finish', False)

        # --- Publishers for required features ---
        self.button_pub = self.create_publisher(ButtonState, '~/button', 1)
        self.battery_pub = self.create_publisher(UInt16, '~/battery', 1)

        # --- Subscriptions for required features ---
        self.create_subscription(MotorsState, '~/set_motor', self.set_motor_state, 10)
        self.create_subscription(SetPWMServoState, '~/pwm_servo/set_state', self.set_pwm_servo_state, 10)
        self.create_subscription(Bool, '~/enable_reception', self.enable_reception, 1)
        # Optional: Keep Led and Buzzer if you might use them for debugging
        self.create_subscription(LedState, '~/set_led', self.set_led_state, 5)
        self.create_subscription(BuzzerState, '~/set_buzzer', self.set_buzzer_state, 5)
        
        # --- Services for required features ---
        self.create_service(GetPWMServoState, '~/pwm_servo/get_state', self.get_pwm_servo_state)

        self.load_servo_offsets()

        # Set initial motor speed to zero at startup
        self.board.set_motor_speed([[1, 0], [2, 0], [3, 0], [4, 0]])

        self.clock = self.get_clock()

        # Timer for periodically publishing sensor data (battery, buttons)
        timer_period = 0.05  # 20Hz
        self.pub_timer = self.create_timer(timer_period, self.pub_callback)

        self.create_service(Trigger, '~/init_finish', self.get_node_state)
        self.get_logger().info('Simplified ros_robot_controller started')

    def load_servo_offsets(self):
        # This function remains unchanged, assuming servo offsets are still needed.
        config_path = '/home/ubuntu/software/Servo_upper_computer/servo_config.yaml'
        try:
            with open(config_path, 'r') as file:
                config = yaml.safe_load(file)

            if not isinstance(config, dict):
                self.get_logger().error(f"Invalid YAML config format: {config_path}")
                return

            for servo_id in range(1, 5):
                offset = config.get(servo_id, 0)
                try:
                    self.board.pwm_servo_set_offset(servo_id, offset)
                    self.get_logger().info(f"Set servo offset for ID {servo_id} to {offset}")
                except Exception as e:
                    self.get_logger().error(f"Failed to set offset for servo {servo_id}: {e}")

        except FileNotFoundError:
            self.get_logger().error(f"Config file not found: {config_path}")
        except yaml.YAMLError as e:
            self.get_logger().error(f"Error parsing YAML file: {e}")
        except Exception as e:
            self.get_logger().error(f"Failed to load servo offsets: {e}")

    def get_node_state(self, request, response):
        response.success = True
        return response

    def pub_callback(self):
        # Simplified to only read necessary data
        if getattr(self, 'enable_reception', False):
            # No lock needed here as get_* methods are now thread-safe by being non-blocking
            button_data = self.board.get_button()
            battery_data = self.board.get_battery()

            if button_data is not None:
                self.pub_button_data(self.button_pub, button_data)
            
            if battery_data is not None:
                self.pub_battery_data(self.battery_pub, battery_data)

    def enable_reception(self, msg):
        self.get_logger().info(f"Setting reception to: {msg.data}")
        self.enable_reception = msg.data
        self.board.enable_reception(msg.data)

    def set_motor_state(self, msg):
        data = []
        for i in msg.data:
            data.extend([[i.id, i.rps]])
        self.board.set_motor_speed(data)

    def set_pwm_servo_state(self, msg):
        data = []
        for i in msg.state:
            if i.id and i.position:
                data.extend([[i.id[0], i.position[0]]])
            if i.id and i.offset:
                self.board.pwm_servo_set_offset(i.id[0], i.offset[0])

        if data:
            self.board.pwm_servo_set_position(msg.duration, data)
            
    # --- Optional methods (can be removed if not needed) ---
    def set_led_state(self, msg):
        # self.board.set_led(msg.on_time, msg.off_time, msg.repeat, msg.id)
        pass # Commented out to avoid using it unless necessary

    def set_buzzer_state(self, msg):
        # self.board.set_buzzer(msg.freq, msg.on_time, msg.off_time, msg.repeat)
        pass # Commented out to avoid using it unless necessary
        
    def get_pwm_servo_state(self, request, response):
        states = []
        for i in request.cmd:
            data = PWMServoState()
            if i.get_position:
                state = self.board.pwm_servo_read_position(i.id)
                if state is not None:
                    data.position = [state]
            if i.get_offset:
                state = self.board.pwm_servo_read_offset(i.id)
                if state is not None:
                    data.offset = [state]
            states.append(data)
        response.state = states
        response.success = True
        return response

    def pub_battery_data(self, pub, data):
        if data is not None:
            msg = UInt16()
            msg.data = data
            pub.publish(msg)

    def pub_button_data(self, pub, data):
        if data is not None:
            key_id, key_event = data
            state_map = {
                PacketReportKeyEvents.KEY_EVENT_PRESSED: 1,
                PacketReportKeyEvents.KEY_EVENT_LONGPRESS: 2,
                PacketReportKeyEvents.KEY_EVENT_LONGPRESS_REPEAT: 3,
                PacketReportKeyEvents.KEY_EVENT_RELEASE_FROM_LP: 4,
                PacketReportKeyEvents.KEY_EVENT_RELEASE_FROM_SP: 0,
                PacketReportKeyEvents.KEY_EVENT_CLICK: 5,
                PacketReportKeyEvents.KEY_EVENT_DOUBLE_CLICK: 6,
                PacketReportKeyEvents.KEY_EVENT_TRIPLE_CLICK: 7,
            }
            state = state_map.get(key_event, -1)
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

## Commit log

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2025-09-01 feat(planning): Implement robust move-and-scan obstacle detection
    Refactors the obstacle planning sequence to perform detection while the robot is in motion, significantly improving both efficiency and robustness.
    This commit replaces the previous "stop-and-scan" method with a new "move-and-scan" state machine flow. The key changes are:
    - **Concurrent Scanning:** The robot now starts scanning for obstacles only when it gets within a specified distance (`planning_scan_start_dist_m`) of the corner, collecting multiple frames as it moves forward. This eliminates the dedicated stopping time for scanning.
    - **Refined State Machine:**
    - `PRE_PLANNING_ADJUST` substate has been removed.
    - `PO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
2025-09-03 feat(planning): Implement max blob area detection with scan throttling
    Refactors the obstacle planning logic to identify the largest color blob instead of using total pixel area. This improves robustness against noise. Also introduces scan frequency control.
    - **Max Blob Detection:** The core detection logic now uses `cv2.connectedComponentsWithStats` to find the largest contiguous area (blob) for each color in every scanned frame. The maximum blob area encountered during the entire scan sequence is now used for the final decision, replacing the previous pattern-based majority vote system.
    - **Scan Frequency Throttling:** A new ROS parameter `planning_scan_interval` has been added to contr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
2025-09-09 feat(camera): Add dynamic tilt stabilization using IMU
    Implement a mechanism to dynamically adjust the camera's tilt angle
    to compensate for the robot's yaw deviation. This keeps the camera
    aimed at a consistent world-frame angle during movement.
    The primary goal is to stabilize the view during the planning phase
    (`PLAN_NEXT_AVOIDANCE`), ensuring more reliable obstacle detection
    by preventing the ROI from shifting due to yawing motion.
2025-09-09 refactor(avoidance): Unify AVOID_OUTER_PASS_THROUGH into ALIGN_WITH_OUTER_WALL
    Refactor the outer wall avoidance sequence by merging the logic from
    `AVOID_OUTER_PASS_THROUGH` directly into the `ALIGN_WITH_OUTER_WALL` state.
    This simplifies the state machine by removing a sub-state. A new helper
    function, `_has_passed_obstacle`, is introduced to handle the completion
    check, while the PID driving logic is now unified under
    `_execute_pid_alignment`.
2025-09-15 feat(kinematics): Adapt control for improved chassis hardware
    - Increased max steering angle to 50 degrees.
    - Added servo offset parameter to correct center alignment.
    - Inverted drive motor direction to match new wiring.
    These changes leverage the upgraded chassis's agility and correct
    for new hardware characteristics.
    [ackermann_original.py]
2025-09-16 feat(maneuver): Revamp turning logic for high-agility chassis
    This commit replaces the old, complex turn-and-reverse maneuver with a
    new, simplified turning sequence (`EXECUTE_TURN`). The new logic leverages
    the improved agility of the v2 chassis to perform faster, more direct
    turns without reversing.
    Key changes:
    - Replaced multi-state reverse maneuvers (APPROACH, REVERSE) with a
    single, two-phase `EXECUTE_TURN` state (approach and pivot).
    - Removed the now-obsolete `_is_turn_maneuver_required` function and
    all associated states and parameters.
    - Cleaned up dead code, including unused variables and deprecated
    turning-related parameters.
2025-09-16 fix(kinematics): Resolve double servo offset application
    Fixed a bug where a software-level servo offset was incorrectly
    applied in `ackermann_original.py`, causing unintended steering adjustments
    during straight-line commands (`angular_speed = 0`).
    The kinematics model is now corrected to assume a pure neutral value (1500),
    fully unifying the physical servo center calibration into the low-level
    controller's `servo_config.yaml`. This ensures consistent and predictable
    steering behavior.
    [ackermann_original.py]
2025-09-18 chore(debug): Add detailed logs and tune parameters for cornering
    - Added extensive debug logging to the `_check_for_corner` function
    to facilitate analysis of corner detection failures.
    - Adjusted the `inner_wall_disappear_threshold` parameter as a
    workaround for LiDAR ground detection issues on outer curves.
    - Tuned various parameters (`avoid_outer_approach_angle_deg`, etc.)
    to improve stability with the new high-agility chassis.
2025-09-18 refactor(maneuver): Stabilize pre-turn movements using PID alignment
    Refactored the pre-turn forward and reverse movements to use the robust
    PID wall alignment logic (`_execute_pid_alignment`), replacing the
    previous unstable controls.
    - `PLAN_NEXT_AVOIDANCE` (forward) now maintains a consistent distance
    from the wall instead of relying only on IMU heading.
    - `POSITIONING_REVERSE` and `PRE_SCANNING_REVERSE` (backward) now
    also use PID alignment for stable, straight reversing.
    - Implemented logic to intelligently reference the outer wall for
    alignment when the inner wall is occluded, particularly after
    an inner-path maneuver.
    - Fixed a `TypeError` caused by the updated `_execute_pid_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
2025-09-20 refactor(maneuver): Improve turn sequence and alignment stability
    This commit refactors the turning and alignment logic to better suit
    the new high-agility chassis, focusing on stability and predictability.
    - **Simplified Turning Maneuver**: Replaced the complex reverse-turn
    logic with a streamlined `EXECUTE_TURN` state. The new sequence
    consists of a PID-controlled approach to the corner, followed by a
    direct, high-steer pivot turn.
    - **Stabilized Pre-Turn Movements**: All pre-turn forward and reverse
    movements (`PLAN_NEXT_AVOIDANCE`, `POSITIONING_REVERSE`, etc.) now
    use the robust PID wall alignment (`_execute_pid_alignment`) for
    more stable and accurate positioning.
    - **Rob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
2025-09-20 feat(imu): Implement robust yaw estimation using NDOF mode
    This commit significantly improves yaw angle accuracy and stability by
    implementing a hybrid approach that leverages the BNO055's IMU and NDOF
    fusion modes, tailored for competition rules.
    ### Key Changes:
    1. **`calibrate_imu.py` (Full Calibration Script)**:
    - A new script to perform a full calibration of the Gyro, Accelerometer,
    and Magnetometer.
    - This is intended to be run once per environment (e.g., at the
    competition venue) to generate a `bno055_full_calibration.json` file.
    2. **`yaw_publisher_node.py` (Hybrid Mode Logic)**:
    - **At Startup (Static)**: The node now starts in `IMU_MODE` (magn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
    [calibrate_imu.py, ros_robot_controller_node.py, yaw_publisher_node.py]
2025-09-26 feat(unparking): Implement parking area start sequence
    Implement a complete state machine for starting from the parking area,
    including pre-detection, strategy selection, and execution.
    - Adds PREPARATION and UNPARKING main states with corresponding sub-states.
    - PREPARATION state determines run direction (CW/CCW) via LiDAR.
    - UNPARKING state performs a pre-detection scan at 45 degrees to
    assess obstacles at the exit.
    - Selects one of four UnparkingStrategy patterns based on direction,
    dominant color, and whether the exit is obstructed.
    - Implements distinct exit maneuvers, including a special reverse action
    for obstructed exits (Pattern 4), before transitioning to the main
    STRAIGHT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
2025-09-30 fix: Resolve intermittent node freezing under high load
    Improves system stability by addressing two root causes of node freezes:
    - The `yaw_publisher_node` was freezing in a 'D' state due to I2C communication hangs. Replaced the I2C library with a timeout-enabled `smbus2` implementation to prevent kernel-level blocking.
    - The `ros_robot_controller` was prone to deadlocks due to heavy lock contention between high-frequency read timers and write command callbacks. Refactored the read timer to minimize lock duration and reduce its frequency, significantly lowering the risk of deadlocks.
    [ros_robot_controller_node.py, yaw_publisher_node.py]
2025-09-30 fix(controller): Harden SDK and simplify controller node
    This commit resolves critical deadlocks and improves the overall stability of the hardware control layer by refactoring the `ros_robot_controller_sdk` and its corresponding ROS 2 node.
    SDK (`ros_robot_controller_sdk.py`):
    - **Resolved Deadlocks:** Implemented a `write_timeout` on the serial port to prevent infinite blocking during write operations, especially when motors are stalled. Write methods now handle `SerialTimeoutException` gracefully.
    - **Simplified Codebase:** Removed unused features such as Bus Servo, Gamepad, SBUS, OLED, and RGB support, tailoring the SDK specifically for the project's needs.
    - **Robust Parsing:** The ser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
    [ros_robot_controller_node.py, ros_robot_controller_sdk.py]
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2025-10-18 fix(controller): Prevent hang by handling zero-speed case in Ackermann kinematics and add steering lookup table
    [ackermann_original.py]
2025-10-19 refactor(turning): Enhance cornering stability and performance
    This commit introduces a series of significant improvements to the cornering maneuver to achieve smoother, more stable, and context-aware turning.
    - **Introduced Dynamic Turn Strategy (`_get_turn_strategy`)**
    - The turning behavior is no longer fixed. It now dynamically selects from 8 different parameter sets (e.g., `turn_outer_to_inner_clear_...`) based on:
    1. The current driving lane (inner/outer).
    2. The planned lane for the next segment.
    3. The presence of an obstacle at the corner's entrance.
    - This allows for optimized turns, such as tighter turns for lane changes and wider, faster turns f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
2025-10-21 feat(parking): Implement final 4-step parking maneuver
    This commit implements the `EXECUTE_PARKING_MANEUVER` sub-state, which performs the final, precise parallel parking action. This completes the autonomous sequence from start to finish.
    ### Key Features:
    - **4-Step Parking Sequence:**
    - The maneuver is broken down into four distinct, sensor-driven steps managed by the `ParkingManeuverStep` enum for robustness:
    1. **Reverse Turn:** Reverses while turning to a precise angle (e.g., 45 degrees) to approach the parking spot, using P-control for accuracy.
    2. **Reverse Straight:** Reverses straight at an angle, using the front LiDAR distance as a trigger to detect when the vehicle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
2025-10-23 feat(parking): Implement full parking sequence and enhance stability
    This commit introduces the complete, multi-step parking maneuver and includes several refinements to improve overall stability and performance during the final lap and parking approach.
    ### Key Features & Refinements:
    - **Implemented Full Parking Maneuver (`EXECUTE_PARKING_MANEUVER`)**
    - A precise, 4-step parallel parking sequence has been implemented:
    1. **Reverse Turn:** Reverses into the spot at a controlled angle.
    2. **Reverse Straight:** Continues reversing until the front LiDAR detects clearance.
    3. **Align Turn:** Reverses with opposite steering to align parallel to the wall.
    4. **Final Adjust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
2025-10-23 feat(parking): Implement new parking sequence and refactor codebase
    This commit introduces a complete, new multi-step parking maneuver and removes the legacy parking logic. It also includes several refinements to improve overall stability and performance during cornering and the final approach.
    ### Major Changes:
    A new, precise, 4-step parallel parking sequence has been implemented, replacing the old logic:
    3. **Align Turn:** Reverses with opposite steering to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
2025-10-26 feat(recovery): Implement dynamic gain adjustment for stuck recovery
    This commit introduces a robust, non-intrusive stuck detection and recovery mechanism. Instead of interrupting the state machine, it dynamically adjusts command gains via a new `_update_recovery_gain` function.
    - **Dynamic Gain Adjustment:**
    - A new function, `_update_recovery_gain`, runs at the end of each control loop to monitor the robot's motion.
    - If the robot is detected as stuck, it modifies `self.recovery_gain` and `self.recovery_angular_gain`, which are then applied in `publish_twist_with_gain`.
    - **Multi-Phase Recovery Strategy:**
    1. **Speed Boost:** Initially, `recovery_gain` is progre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
2025-10-26 refactor(control): Implement dynamic max steer based on speed
    This commit introduces a `_get_dynamic_max_steer()` helper function to calculate the maximum allowable steering angle dynamically based on the current vehicle speed. This resolves issues where the fixed `max_steer` value caused overly aggressive steering at low speeds.
    ### Problem:
    - The constant `self.max_steer` was tuned for the base `forward_speed`.
    - During low-speed maneuvers (e.g., `UNPARKING`, `PARKING`, final phases of turns), this high limit caused P-controlled steering commands to saturate easily, resulting in jerky, "bang-bang" like behavior and overshooting.
    ### Solution:
    - A new helper function, `_get_dynamic_max_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
2025-10-26 fix(node): Stop control loop timer upon finishing run
    Previously, the `control_loop_timer` continued to run even after the node entered the `FINISHED` state. This caused the node to perform unnecessary background processing and produce continuous log spam.
    This commit cancels the `control_loop_timer` within the `_handle_state_finished` method, ensuring that the main control loop stops once the robot's task is complete.
2025-10-26 feat(recovery): Finalize robust multi-phase stuck recovery system
    This commit completes and refines the stuck detection and recovery mechanism, making it more robust, intelligent, and safe.
    ### Key Enhancements:
    - **Expanded Stuck Detection Trigger:**
    - The condition to start the stuck timer is now `is_commanding_motion`, which checks for both `linear` and `angular` commands. This allows the system to correctly detect stalls during turning maneuvers (e.g., `UNPARKING`).
    - **Added Final Resort - Emergency Reverse:**
    - If all progressive recovery attempts (speed boost, angular reduction) fail (`stuck_level >= recovery_max_level`), a final emergency reverse maneuver is now triggered.
    -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
2025-10-26 feat(core, launch): Improve camera node resilience and startup robustness
    This commit introduces two changes to make the system more resilient to failures of the `usb_cam` node.
    1. **Enable Auto-Respawn for usb_cam:**
    - The `usb_cam.launch.py` is modified to include `respawn=True` and `respawn_delay=2.0` for the camera node. This ensures the node automatically restarts if it crashes.
    2. **Implement Infinite Retry for Initial Image Acquisition:**
    - The `_process_pre_unparking_image_callback` in `obstacle_navigator_node.py` is updated to wait indefinitely for the first camera frame.
    - The previous 10-attempt limit has been removed. The node will now wait as long as needed for t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
2025-10-28 fix: Correct velocity calculation in p-controlled turn
    Revised the speed control logic within the `_execute_p_controlled_turn` helper function. The calculation is now based on the remaining angle to the target (`yaw_error_deg`) instead of the elapsed angle from an estimated start point.
    This resolves an issue where turning speed would drop unexpectedly, especially during the final alignment of a lane change.
2025-10-28 fix: Prevent timer cancellation in parking debug mode
    Introduced a `force_start_debug_mode` flag. The `_handle_state_finished` function now checks this flag to avoid canceling the main control loop timer when the parking debug mode is active.
2025-10-28 fix(parking): Enhance robustness of approach maneuver
    Added multiple safety conditions to the completion check in the parking approach phase (`_handle_parking_sub_approach_parking_start`) to prevent premature stops.
    The previous logic could be falsely triggered by the parking lot poles if the robot was not perfectly aligned with the wall.
    Changes include:
    - **Yaw Alignment Check:** The approach now only completes if the robot's yaw deviation is within a new configurable tolerance (`parking_approach_yaw_tolerance_deg`). This ensures the robot is straight before checking the distance.
    - **Minimum Distance Threshold:** A minimum front distance (`parking_approach_min_front_dist_m`) is now requ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
2025-10-28 refactor(parking): Refine trigger condition for IMU_ONLY mode in approach
    Adjusted the condition that activates the `IMU_ONLY` alignment mode during the parking approach (`_handle_parking_sub_approach_parking_start`).
    The previous implementation switched to `IMU_ONLY` mode as soon as the robot entered the slowdown zone (`front_dist < 1.3m`). This was found to be too aggressive, as it disabled LiDAR-based distance control prematurely, sometimes causing the robot to drift away from the wall.
    The trigger condition has been changed to a much narrower window (`0.97m < front_dist < 1.05m`). This ensures that LiDAR-based wall alignment remains active for a longer duration, improving path stabilit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
2025-10-29 fix(parking): Ensure final forward adjustment in step 4 executes reliably
    Modified the final step of the parking maneuver (`_parking_step4_final_adjust`) to use a timer for state transition.
    Previously, the `FINISHED` state was set immediately after publishing the forward command, creating a race condition where the stop command from `_handle_state_finished` could override it.
    The new implementation continuously sends the forward command for a configurable duration (`parking_step4_duration_sec`) before a timer callback safely transitions the state to `FINISHED`. This guarantees the final wheel alignment movement is consistently performed.
2025-10-29 refactor(parking): Deactivate step 2 (reverse straight) of parking maneuver
    Deactivated the logic within `_parking_step2_reverse_straight` by commenting it out and implementing an immediate transition to step 3.
    **Reasoning:**
    In the current tuning, the combination of the approach phase and step 1 (reverse turn) already places the robot in a sufficient position for the final alignment. The additional straight reverse movement in step 2 was found to be redundant and could potentially cause the robot to back up too far.
    By skipping this step, the parking sequence becomes simpler and more robust against potential miscalculations of the front distance trigger. The original logic has been prese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
2025-10-29 fix(core): Ensure reliable stop command on run completion
    Refactored the `FINISHED` state handling to resolve two issues: a race condition causing the robot to sometimes continue moving after parking, and persistent debug log output after stopping.
    **Changes:**
    1. **Unified Stop Command:** Command publishing is now exclusively handled by the main control loop. The `_finish_parking_maneuver` timer callback is now only responsible for setting the state to `FINISHED`.
    2. **Persistent Stop Signal:** The `control_loop_timer` is no longer canceled in `_handle_state_finished`. This ensures that a `(0.0, 0.0)` velocity command is continuously published once the `FINISHED` state is reached.
    3. **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
2025-10-29 feat(alignment): Overhaul ESTIMATED/IMU_ONLY logic for inner wall alignment
    Introduced a new, more comprehensive set of conditions within `_execute_pid_alignment` to determine when to use `ESTIMATED` or `IMU_ONLY` modes during inner wall alignment (`ALIGN_INNER`).
    The previous `ESTIMATED` mode was only active during post-avoidance alignment (`is_in_avoidance_alignment`). This change makes the logic always-on for `ALIGN_INNER`, allowing the robot to react to a lost inner wall or abnormal track geometry at any time.
    **New Logic:**
    1. The special handling block is now triggered if:
    - `front_dist` is outside the stable range (1.05m - 1.95m).
    - `course_width` is outside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
2025-10-31 feat: Initial implementation of OpenNavigatorNode
    This commit introduces `OpenNavigatorNode`, a streamlined navigator designed for high-speed laps on an open (obstacle-free) course.
    The node is based on a simplified version of `ObstacleNavigatorNode`, inheriting its robust core features while removing complexities unnecessary for an open course.
    **Key Changes:**
    - **Created `OpenNavigatorNode`:** Ported the core structure from `ObstacleNavigatorNode`.
    - **Simplified State Machine:** Reduced states to `PREPARATION`, `STRAIGHT`, `TURNING`, and `FINISHED`, removing all parking, unparking, and obstacle avoidance logic.
    - **Removed Unnecessary Features:** All code related to camera, image proc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
2025-10-31 refactor(navigation): Adjust alignment logic for open course
    This commit includes two refinements to the navigation logic for the `OpenNavigatorNode` to improve performance during cornering and initialization.
    **1. Removed Corner Approach IMU_ONLY Mode**
    The logic that disabled distance control (`IMU_ONLY`) when approaching a corner (`inner_wall_far_counter > 0`) has been removed from `_execute_pid_alignment`.
    Distance-based PID control will now remain active until the corner is entered. This change is intended to maintain a tighter and more consistent line by continuously tracking the outer wall, even in the final moments before a turn.
    **2. Increased Initial Forward Speed**
    The initia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
2025-11-02 feat: Implement and refine OpenNavigatorNode
    This commit introduces the initial, fully functional version of `OpenNavigatorNode`, a streamlined navigator for obstacle-free courses, and includes several key refinements for robustness.
    The node is ported from `ObstacleNavigatorNode`, inheriting its stable core architecture (state machine, pivot turns, stuck recovery) while removing all complexity related to obstacles, parking, and vision.
    **Key Implementation Details:**
    1. **Streamlined Core:**
    - Simplified the state machine to `PREPARATION`, `STRAIGHT`, `TURNING`, `FINISHED`.
    - Removed all code, parameters, and dependencies related to camera, image processing, parking, unparking,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
2025-11-08 docs: Reorganize models directory and update CAD files
    Reorganized the `models` directory into a more structured format: `custom_parts`, `commercial_parts`, and `assemblies`.
    - Renamed existing folders for clarity and corrected typos.
    - Added new folders for assembly diagrams and CAD models of commercial components.
    - Updated all CAD files and blueprints to their latest versions.
    [LiDAR-mid.SLDPRT, LiDAR.SLDPRT, LiDAR2.SLDPRT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]
2025-11-08 docs: Update BOM with new 3D parts and refresh images
    - Overhauled the "Custom 3D-Printed Parts" section in the Bill of Materials (BOM) to reflect the latest set of components.
    - Updated all links to point to the new, reorganized `models` directory structure.
    - Replaced outdated robot photos in the "Vehicle Overview" section with new, high-quality images.
2025-11-08 docs: Overhaul Section 8 for Engineering Factor evaluation
    Completely rewrote Section 8 ("Engineering Design & Manufacturing") to strongly align with the `7. Engineering Factor` scoring criteria and showcase the team's custom design and manufacturing capabilities.
    **Key Additions & Changes:**
    - **Added Design Philosophy:** A new introduction (8.1) now frames the team's approach as "reimagining and re-engineering" the base kit, emphasizing purpose-driven design.
    - **Detailed Core System Redesign:** Section 8.2 now tells the story of redesigning the drive system, explaining the transition from a non-compliant dual-motor setup to a rule-compliant, custom single-motor drive with a mechanical d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
